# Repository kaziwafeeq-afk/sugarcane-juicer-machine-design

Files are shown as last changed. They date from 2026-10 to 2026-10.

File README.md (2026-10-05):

# Design and Analysis of a Conventional Sugarcane Juicer Machine

A comprehensive machine design, MATLAB-automated calculations, and ANSYS structural analysis project for a commercial sugarcane juicer system.

---

## Project Overview
* **Objective:** Design and validate a compact, efficient roadside sugarcane juicer machine capable of handling commercial daily workloads.
* **Core Systems:** Electric motor drive (1.4 HP, 630 rpm), multi-stage pulley and gear reduction systems, crushing rollers, and a structural support frame.
* **Key Tools:** SolidWorks (CAD modeling), ANSYS (Static Structural FEA), MATLAB (Automated Gear Design and Calculations).

---

## Key Specifications & Performance
* **Machine Dimensions:** Height: 1.2 m, Breadth: 0.35 m, Length: 0.5 m.
* **Capacity & Yield:** Processes 20 kg/hour with an average juice yield of 250 ml/kg.
* **Daily Throughput:** Estimated output of 98 cups (24.5 liters) over a 7 hour working day at 70% operational efficiency.

---

## Engineering Methodology

1. **Power Transmission & Layout:**
   * Designed a multi-stage reduction using a 3-phase electric motor connected via pulley systems and gear trains (spur and pinion gears) to achieve high crushing torque at the rollers.
   * Developed automated MATLAB scripts to handle iterative gear sizing, module calculations, and stress validations without manual hand-calculation bottlenecks.

2. **Structural & FEA Analysis (ANSYS):**
   * Conducted static structural analyses on the structural steel side walls, gear teeth, and roller shafts under simulated loading and motor torque moments.
   * **Factor of Safety (FOS):** Maintained robust safety margins across components (e.g., FOS of 5.57 on the main support structure and 15 on gear/pulley subcomponents under exaggerated peak loads).

---

## Assembly Render

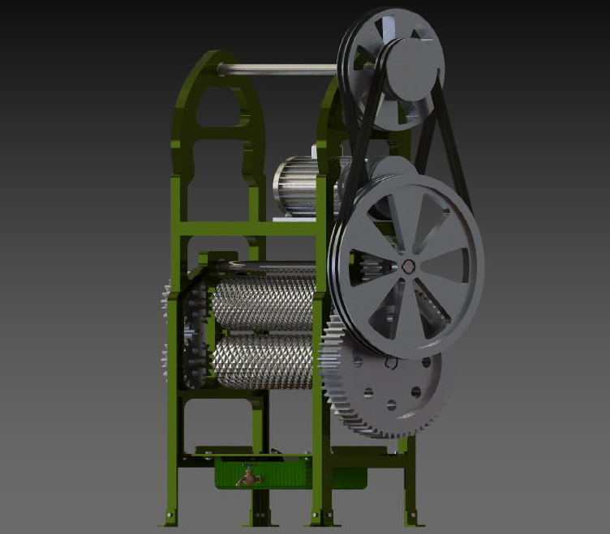
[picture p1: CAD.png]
Sugarcane Juicer CAD Assembly


---

## Documentation & Repository Structure
* **[Download & View Full Project Report (PDF)](./DMS%20ASSIGNMENT%201-1.pdf)**: Complete documentation including detailed calculations, BOM, and ANSYS stress/deformation contour plots.
* `CAD.png`: Isometric assembly render of the machine.

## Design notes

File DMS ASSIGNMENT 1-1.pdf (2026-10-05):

### Member 1

### - Name: Ashutosh Mohapatra - Roll number: 211020003

### Member 2

### - Name: Taran Poojari - Roll number: 211020004

### Member 3

### - Name: Mohammed Wafeeq Kazi - Roll number: 211020022

## Assignment 1

## Design of Machine Elements Project

## Design and Analysis of a Conventional Sugarcane Juicer Machine

## The report outlines the following points –

1.Introduction.

2.Initial layout as per motor specifications.

## 3.Mounting structure, its Analysis

4.layout changes.

5.MATLAB Program for gear calculations.

6.Structural Analysis.

7.Bill Of Quantities.

8.Amount of sugarcane juice collected in a day.

9.Conclusion.

Introduction:

- Sugarcane juicer machines are one of the most common machines manufactured industrially due to the demands and high consumption of the conventional beverage in urban and suburban regions.
- The layout of a basic machine consists of a pulley system driven by an electric motor, which is further connected to a gear system, to which the final rollers are connected to obtain significant speed reduction and crushing power.
- The distance between the rollers is 10-15 mm, which is smaller than the diameter of the sugarcane itself, else the sufficient crushing force would not be developed while extracting the juice from the stalk.
- The roller distance can be varied with the help of a simple mechanism operated by a lead screw-based mechanism. For simplicity, the mechanism is not added in the project and only the fundamental elements are described in the given report. The pictures of a standard sugar cane juicer machine are below:

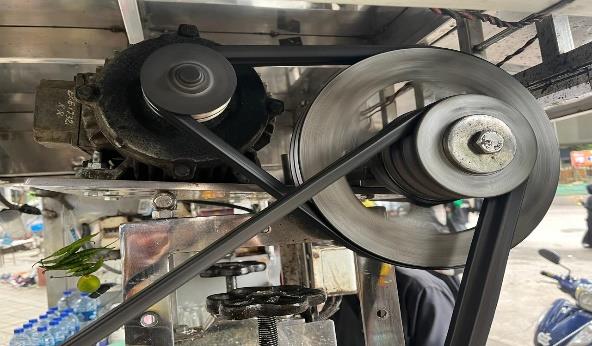
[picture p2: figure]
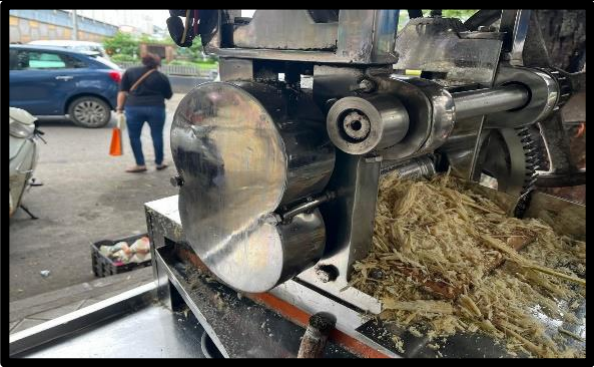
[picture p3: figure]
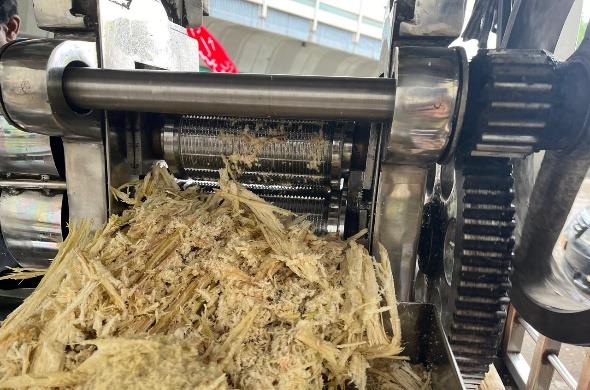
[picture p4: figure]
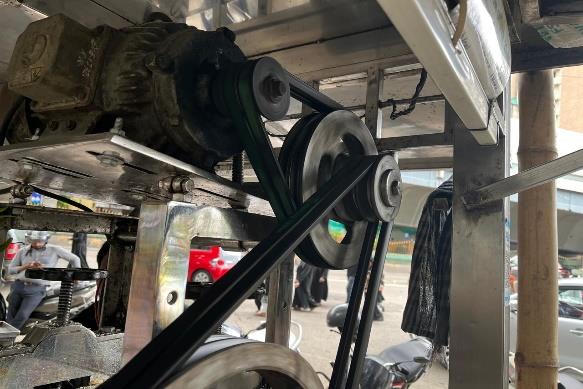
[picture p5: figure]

Initial Layout

- The motor specifications used for this project are as follows:
Type: | 3 - Phase Electric motor:
Power: | 1.4 HP
Speed: | 630 rpm
- Initial Model:

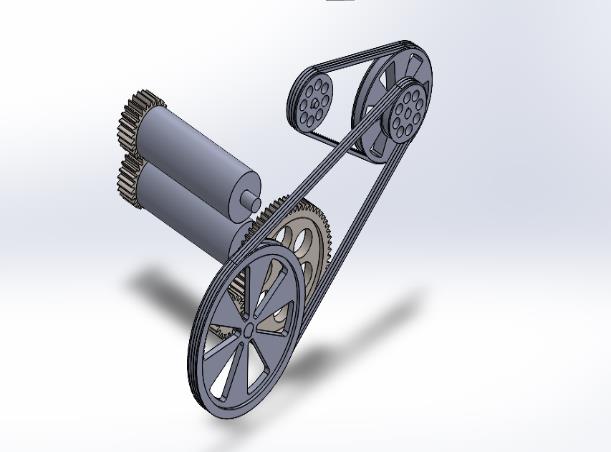
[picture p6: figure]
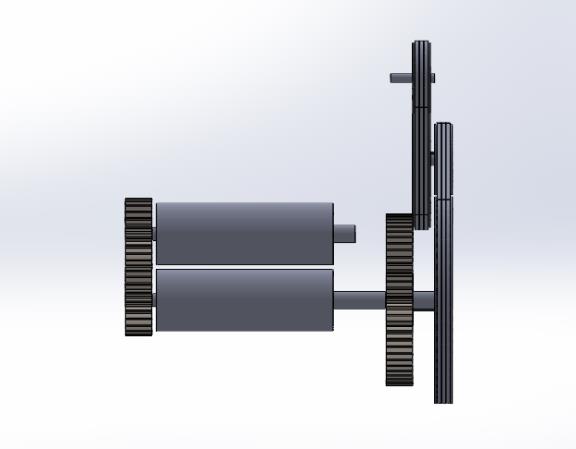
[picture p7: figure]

Fig: Isometric View. | Fig: Front View.

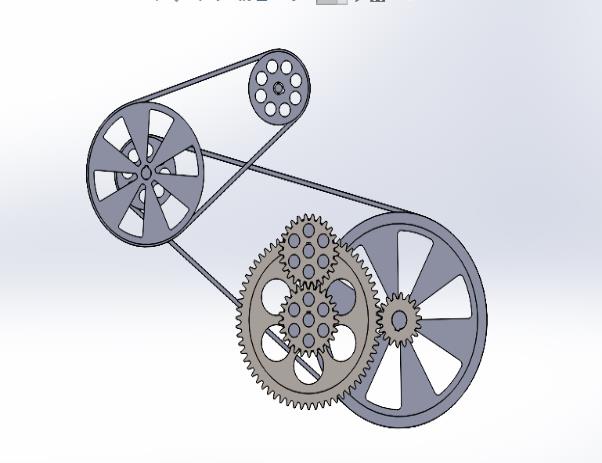
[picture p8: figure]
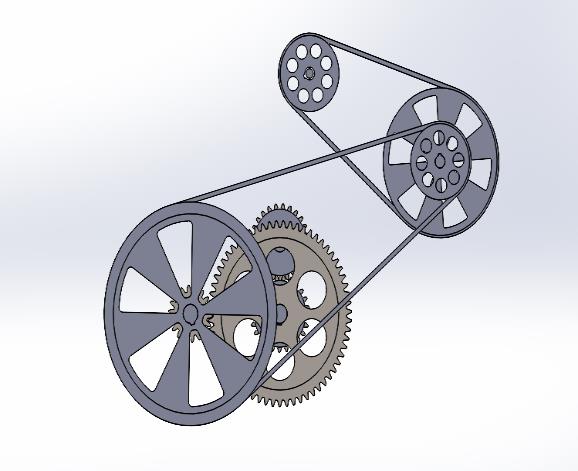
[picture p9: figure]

Fig: Left View | Fig: Right View
- Based on the calculations, the initial layout design was created in SolidWorks as follows.
- The supporting calculations are attached at the end of the report for both the gear and pulley systems.

SUPPORT STRUCTURE

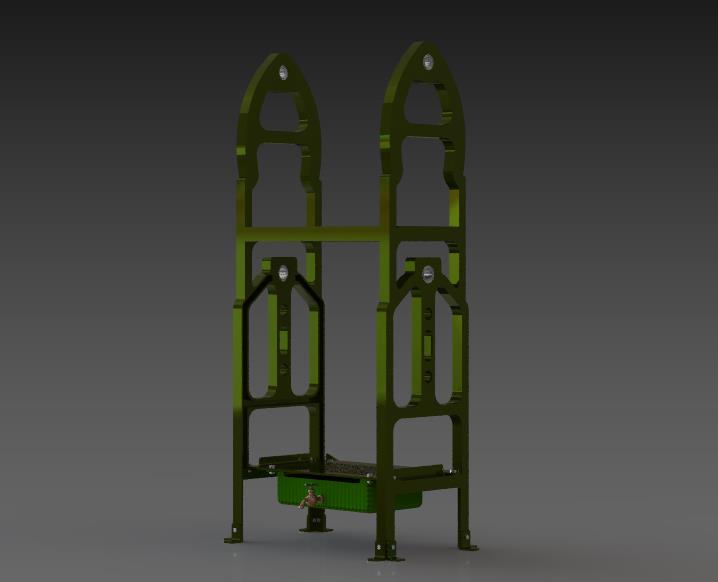
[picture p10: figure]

- The sugarcane machine features a support structure designed to hold the pulleys, gears, motors, and bearings securely in place. The structure includes four designated areas where rotating components are installed, each supported by bearings to ensure smooth operation.
- The upper base of the structure is responsible for supporting the motor, while the lower base incorporates a collection mechanism. When the sugarcane is crushed, the extracted juice flows into a container below. A strainer in this mechanism prevents sugarcane fibre’s from mixing with the juice.
- In this setup, the primary load is borne by the side walls of the structure. The loads on the collection chamber and motor base are considered minimal and not significant enough to impact the overall structural integrity.
- Therefore, we will be doing the Analysis of the side walls to ensure the stability of the structure.

Analysis of static structure which provides support to the crushing mechanism of the sugarcane machine:

- Material Used:
- Structural Steel is used for this purpose for providing robust support to the mechanisms.
- E = 200 GPa.
- P.R = 0.3.
- Analysis Settings:
- A: Fixed to the ground.
- B: Fixed to the ground.
- C: Moment due to presence of gear/ pulley.
- D: Moment due to presence of gear/ pulley.
- E: Moment due to presence of gear/ pulley.
- F: Moment due to presence of gear/ pulley.
- G: Load due to Collection mechanism.
- H: load due to motor.
- Note: Exaggerated loads and moments are applied as a factor of safety.

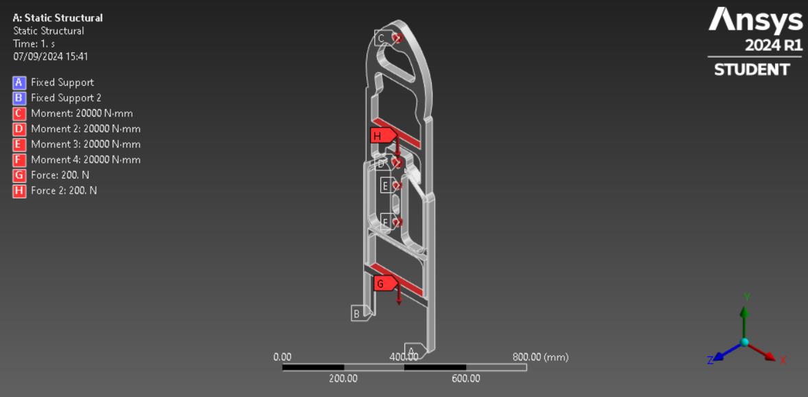
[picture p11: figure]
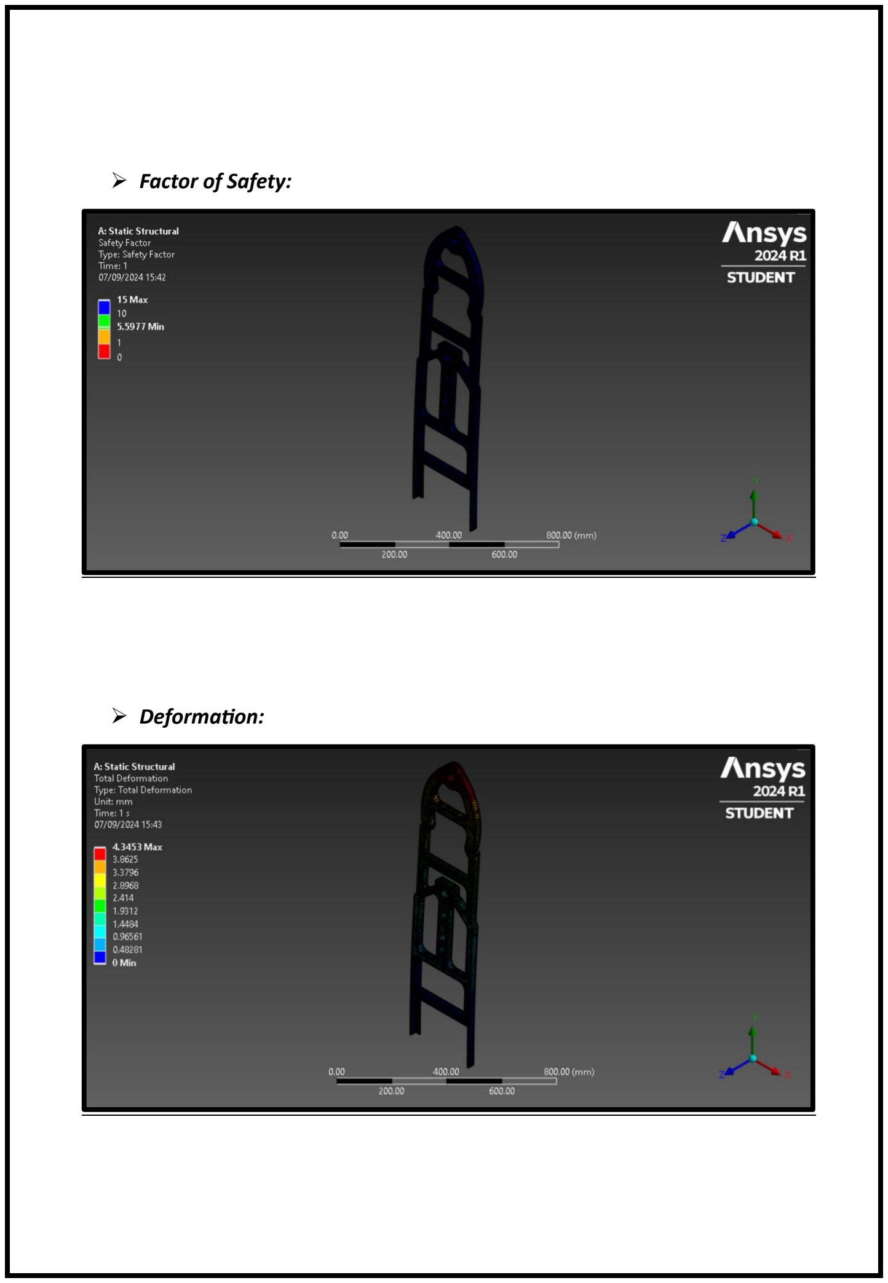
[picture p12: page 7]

- Factor of Safety:
- Deformation:

- Equivalent Stress:

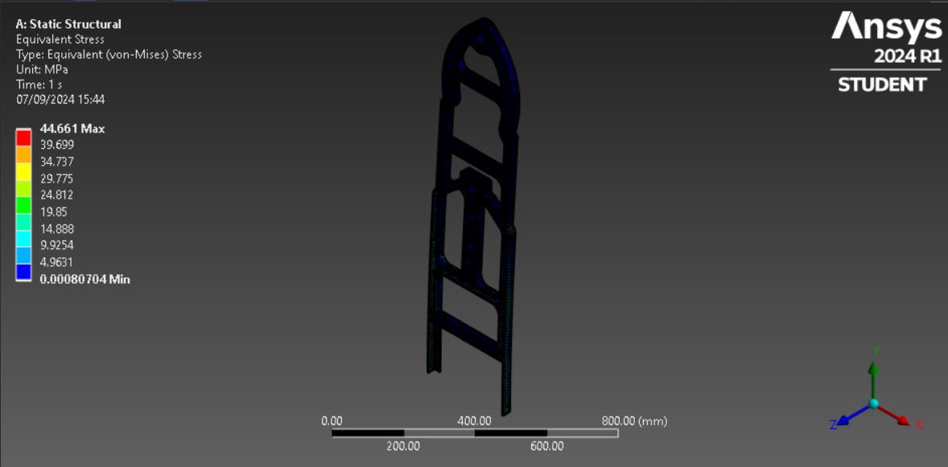
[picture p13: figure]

- Results:
- The mechanism will be able to sustain the applied load as the factor of safety is 5.57.
- The gears are supported using two side walls and the load in unevenly distributed on both sides.
- The analysis done is of the wall experiencing greater load. So therefore, we can say that the side experiencing less load in comparison to other side will also sustain.

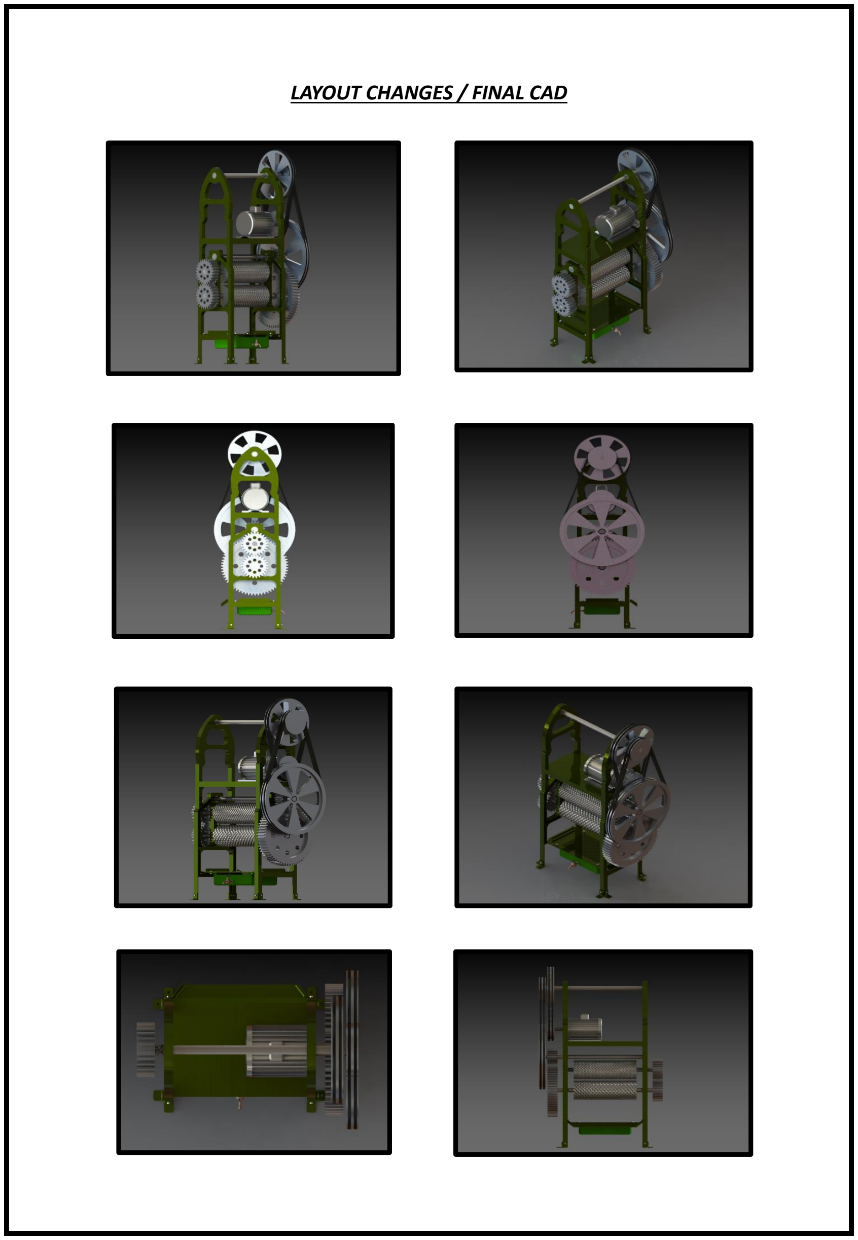
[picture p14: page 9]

LAYOUT CHANGES / FINAL CAD

Final CAD

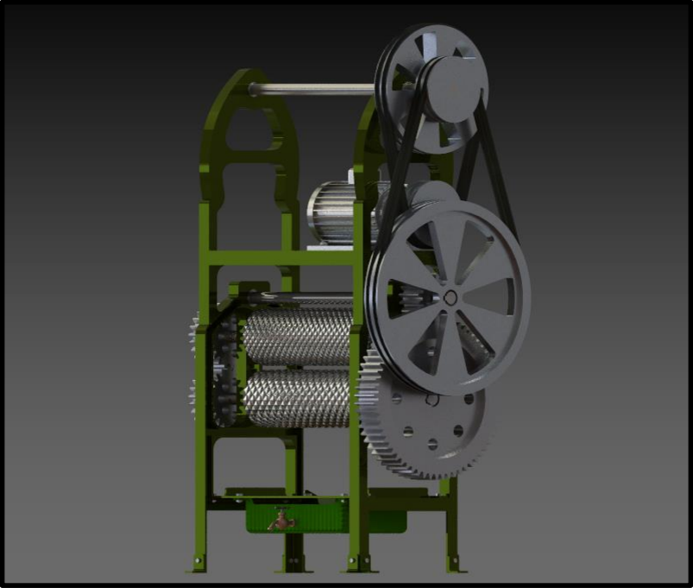
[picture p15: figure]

- The Mechanical System Comprising of pulleys, gears, rollers, support structure and motor where connected/assembled in such a way so as to provide a compact structure.
- The dimensions of the Sugarcane machine are roughly
- Height: 1.2 meter.
- Breadth: 0.35 meter.
- Length: 0.5 meter.
- The Components which will rotate are provided with bearings to provide a smooth frictionless Rotations.
- The Gears and Pulleys are mated with suitable keys to provide stable locking with interconnected shafts.
- The Rollers are provided with grooves which amplifies the crushing effect.
- A tap is fitted on the container, providing feasible collection of crushed juice.

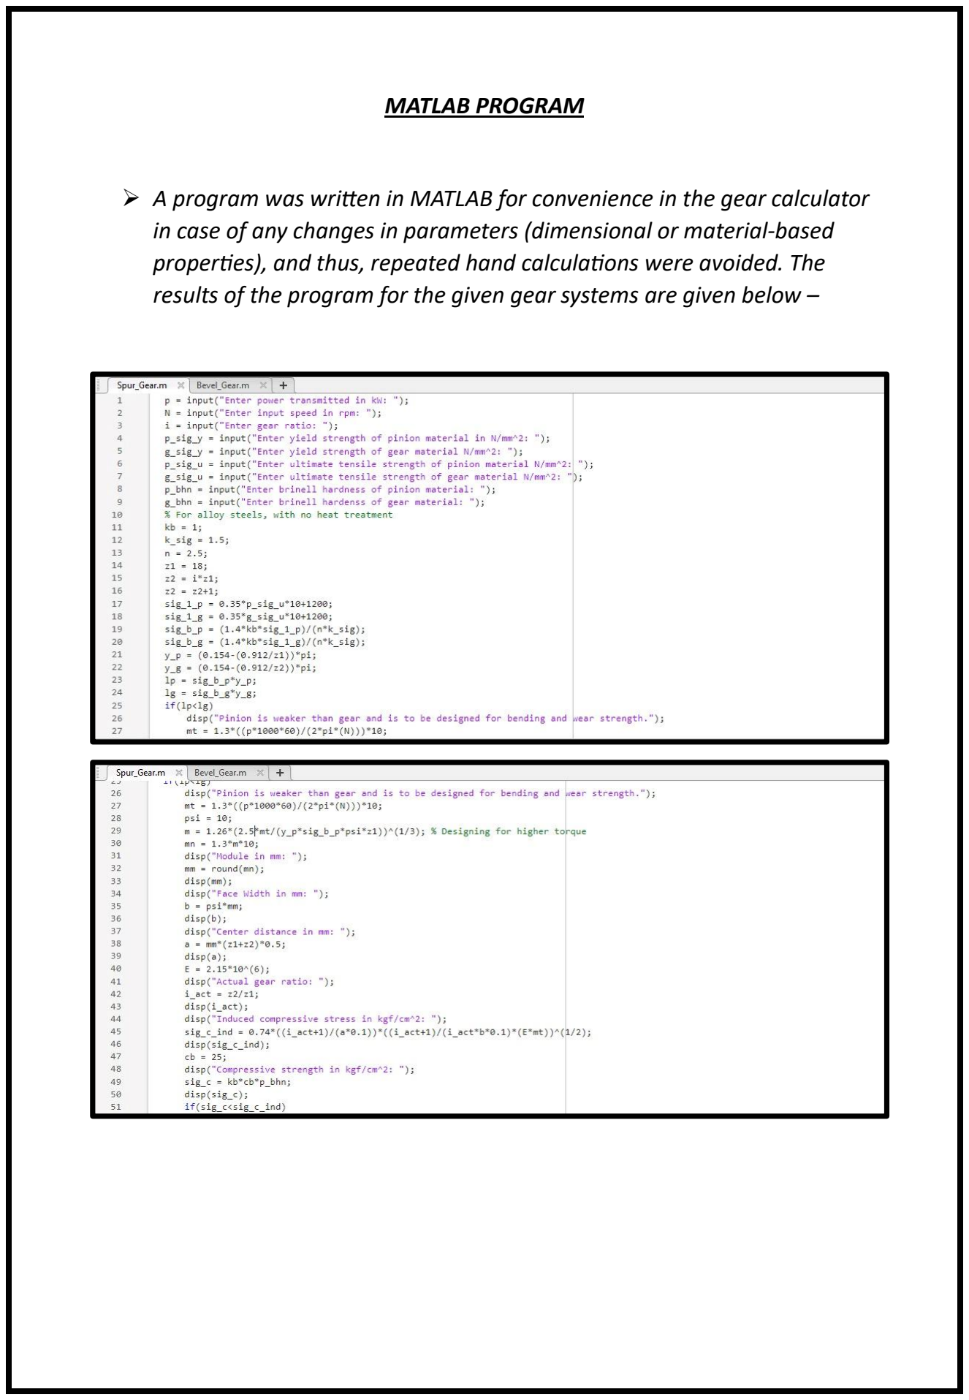
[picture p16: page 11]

MATLAB PROGRAM

- A program was written in MATLAB for convenience in the gear calculator in case of any changes in parameters (dimensional or material-based properties), and thus, repeated hand calculations were avoided. The results of the program for the given gear systems are given below –

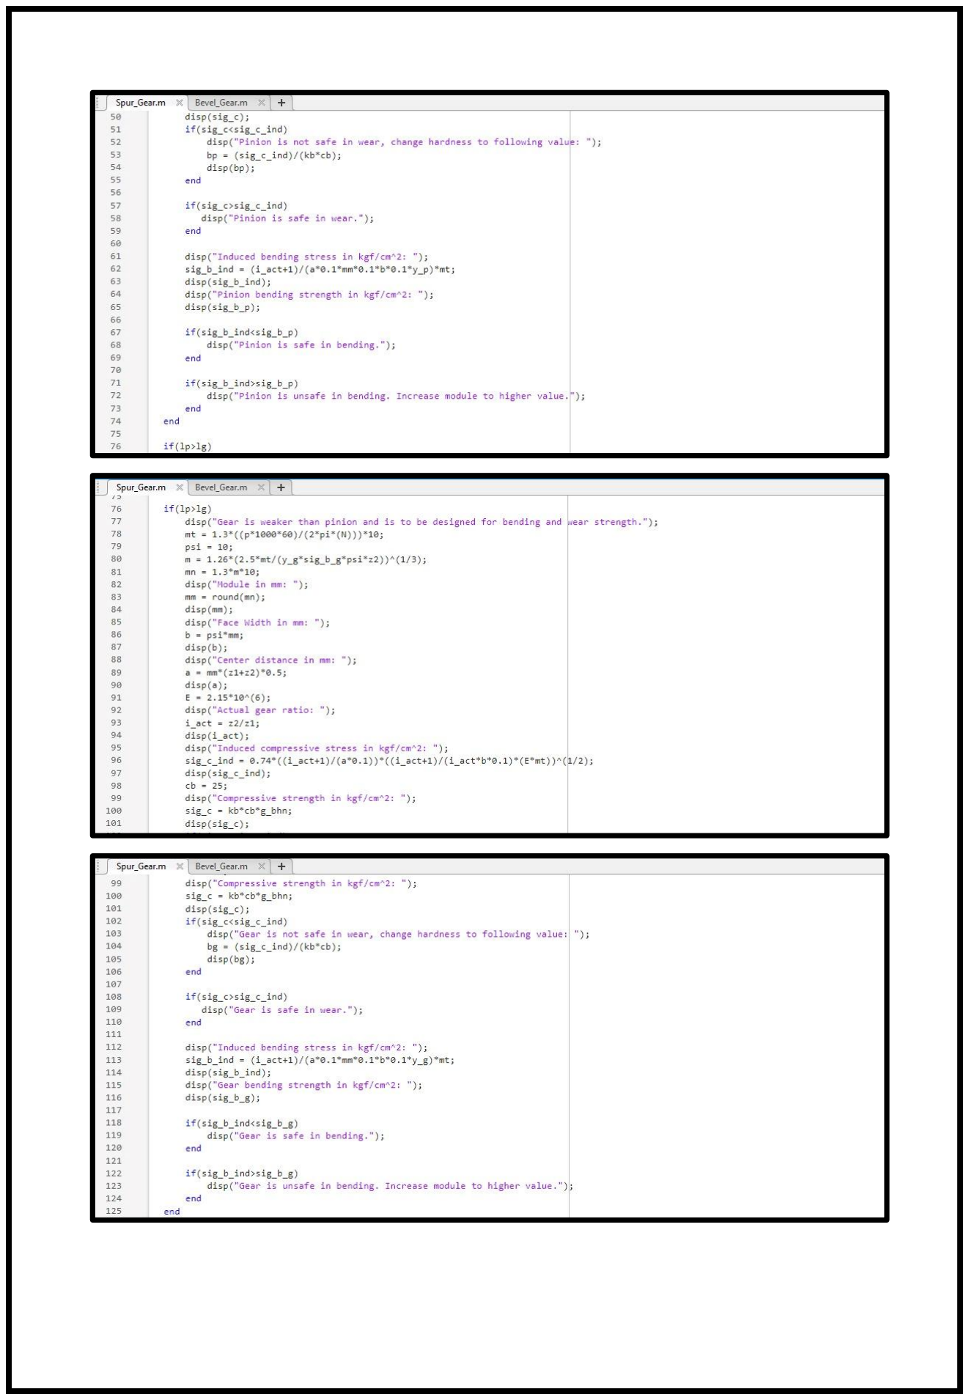
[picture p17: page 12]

- Results:

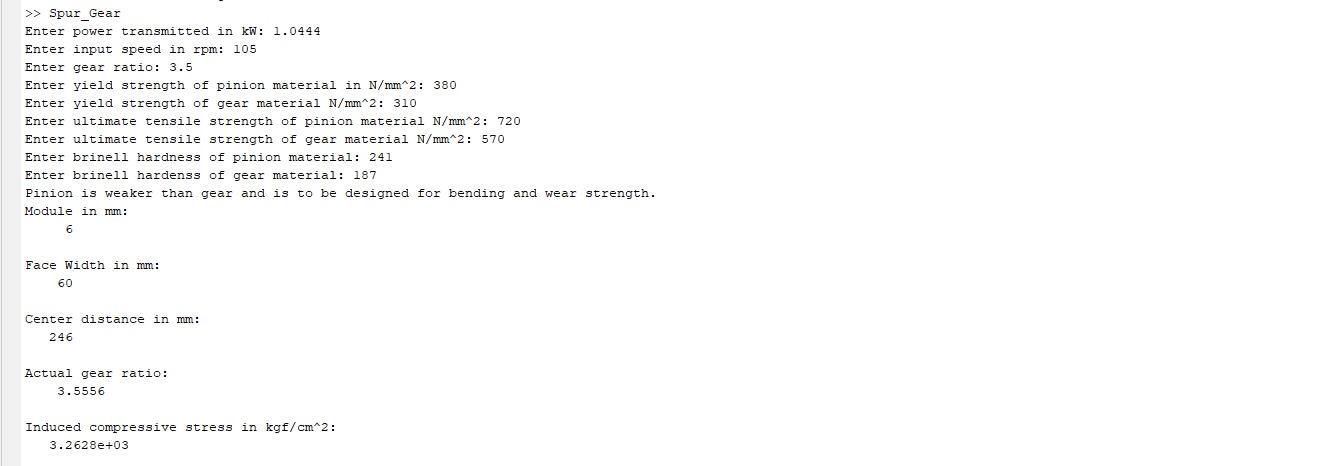
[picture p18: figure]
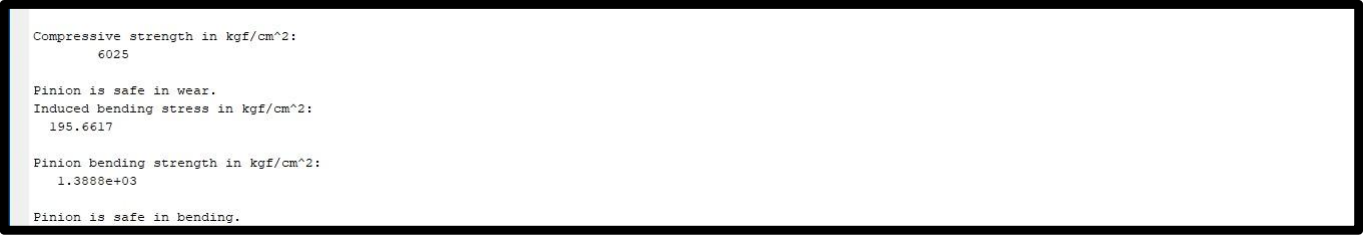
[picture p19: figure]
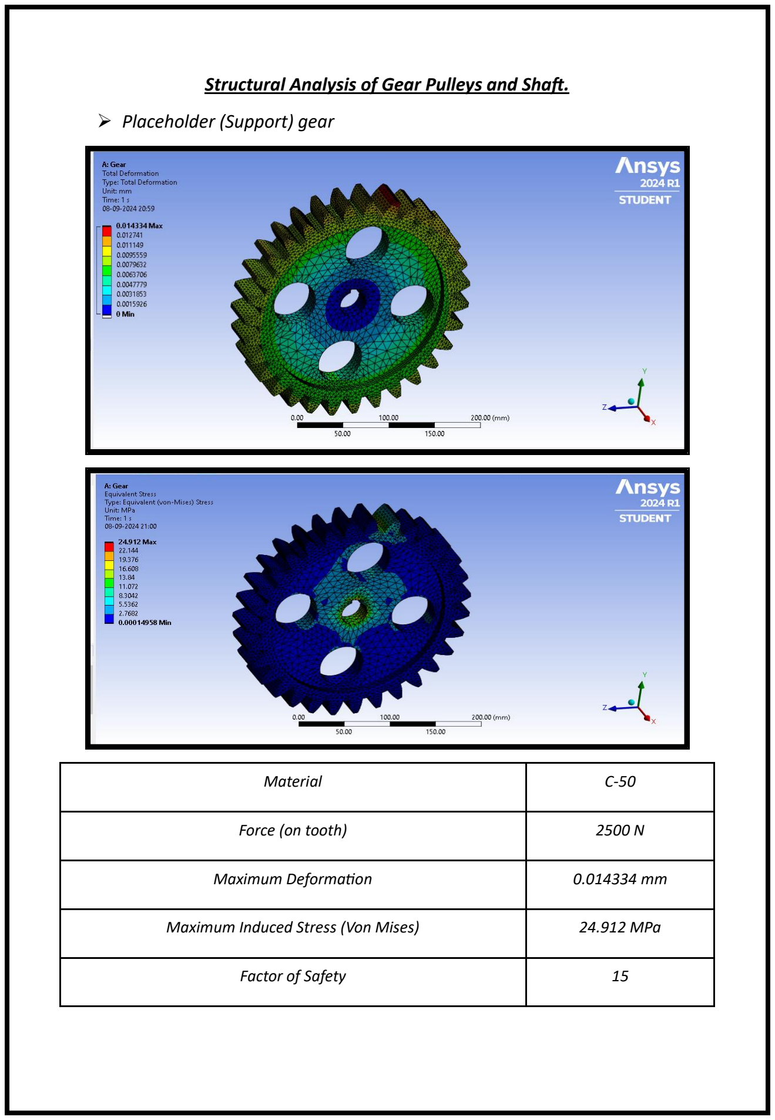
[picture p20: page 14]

Structural Analysis of Gear Pulleys and Shaft.

- Placeholder (Support) gear
Material | C-50
Force (on tooth) | 2500 N
Maximum Deformation | 0.014334 mm
Maximum Induced Stress (Von Mises) | 24.912 MPa
Factor of Safety | 15

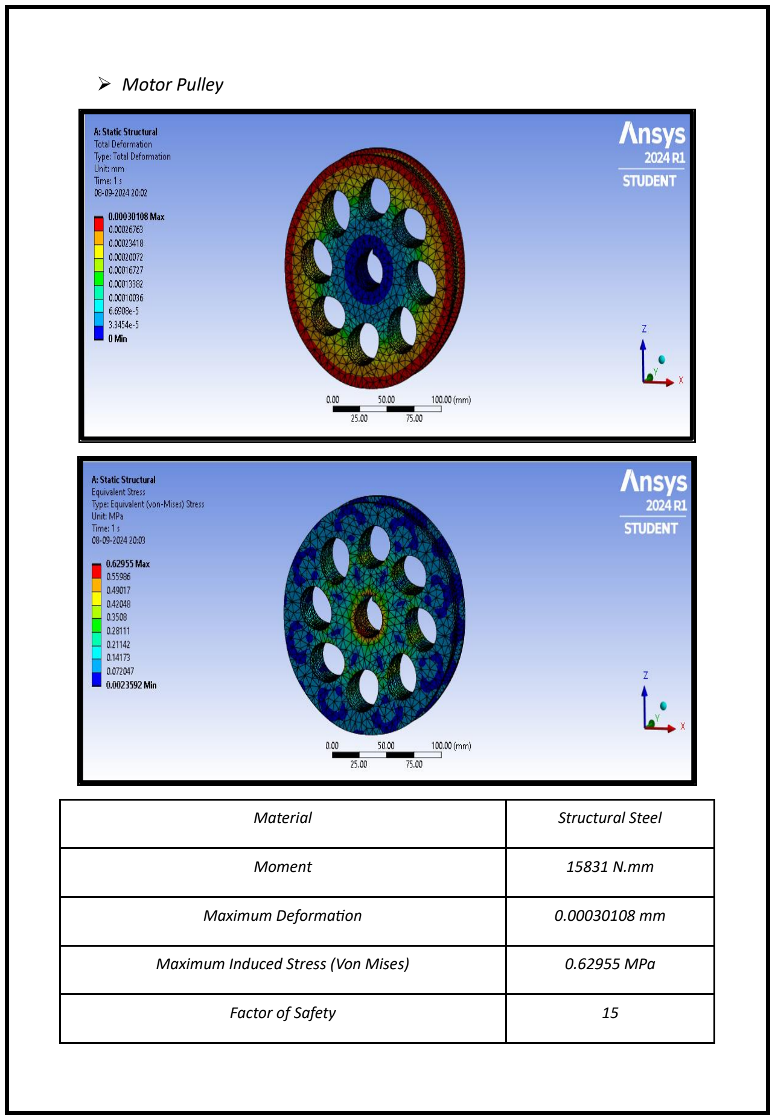
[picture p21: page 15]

- Motor Pulley
Material | Structural Steel
Moment | 15831 N.mm
Maximum Deformation | 0.00030108 mm
Maximum Induced Stress (Von Mises) | 0.62955 MPa
Factor of Safety | 15

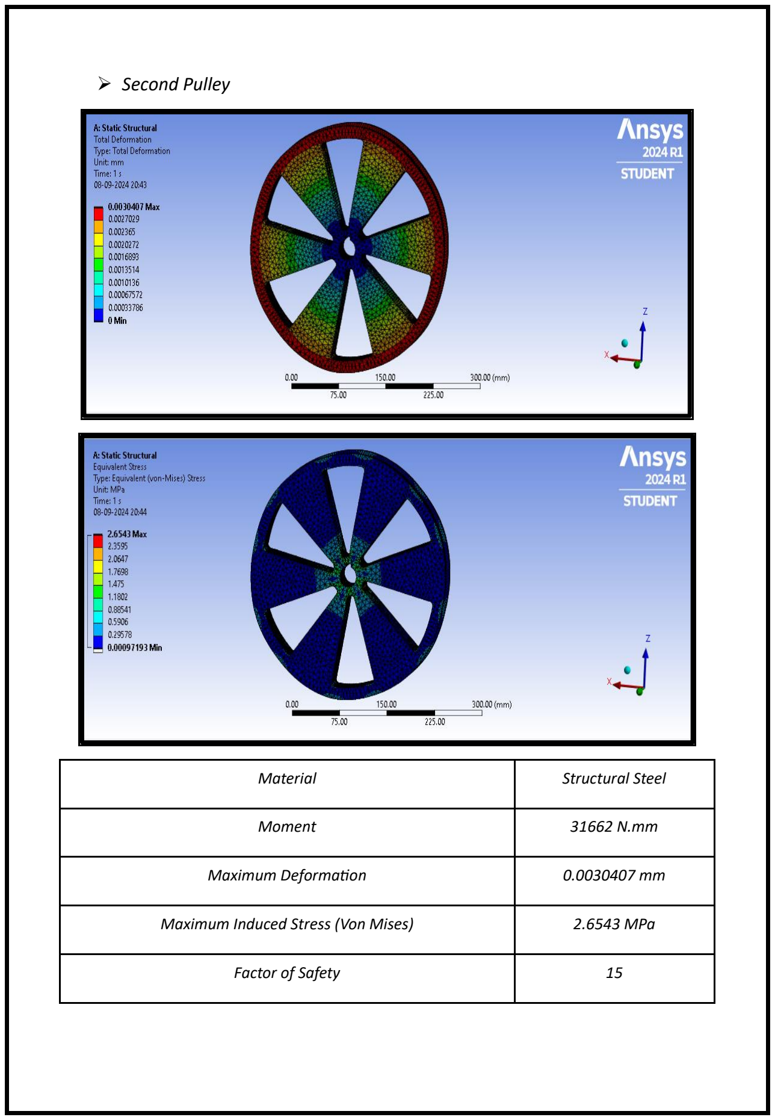
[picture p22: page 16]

- Second Pulley
Material | Structural Steel
Moment | 31662 N.mm
Maximum Deformation | 0.0030407 mm
Maximum Induced Stress (Von Mises) | 2.6543 MPa
Factor of Safety | 15

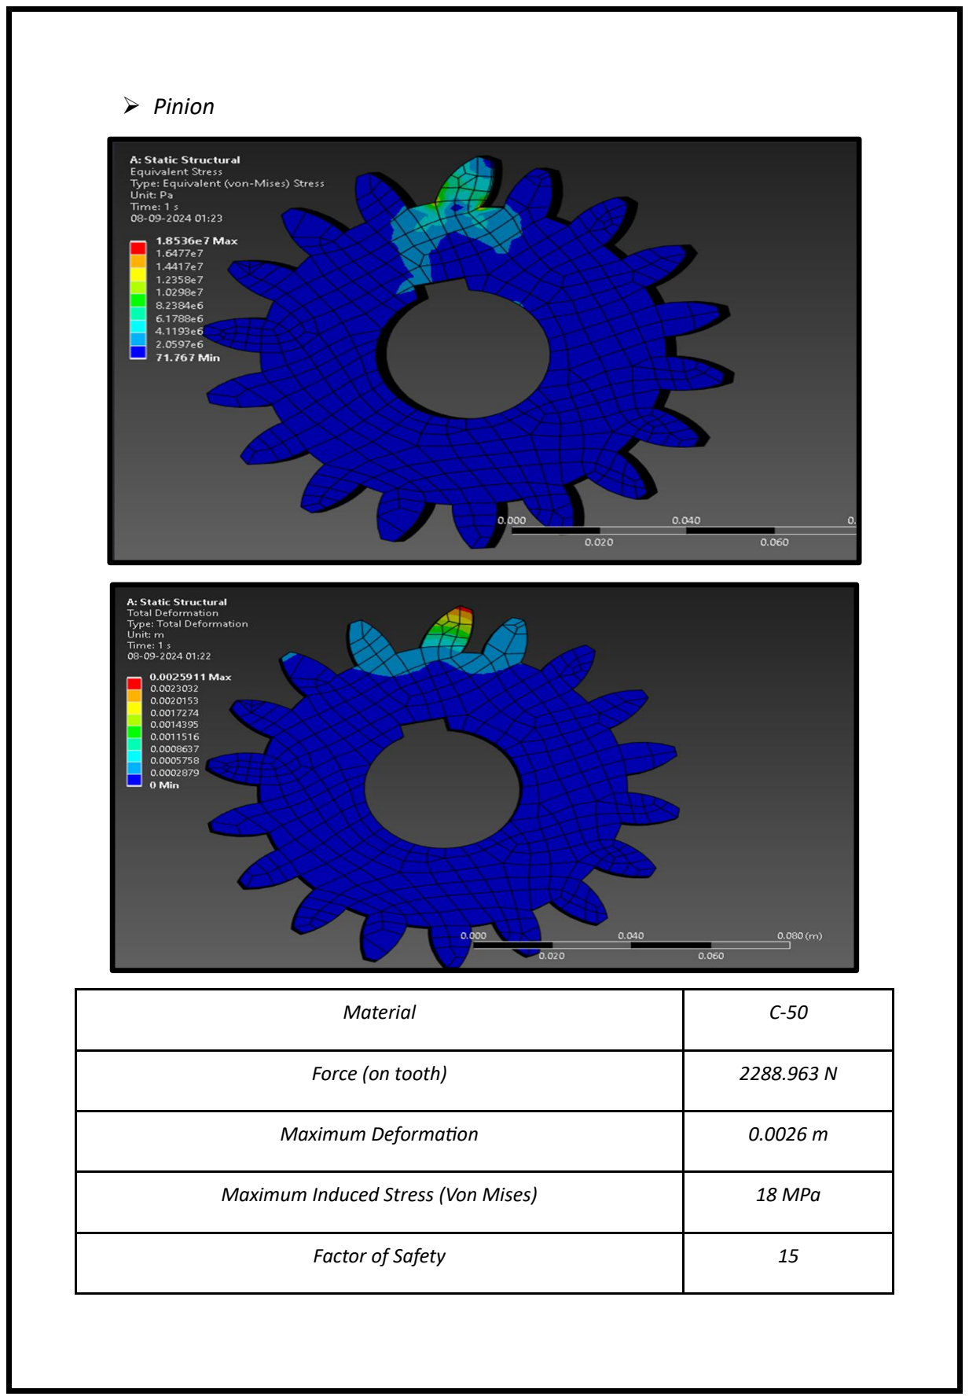
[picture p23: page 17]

- Pinion
Material | C-50
Force (on tooth) | 2288.963 N
Maximum Deformation | 0.0026 m
Maximum Induced Stress (Von Mises) | 18 MPa
Factor of Safety | 15

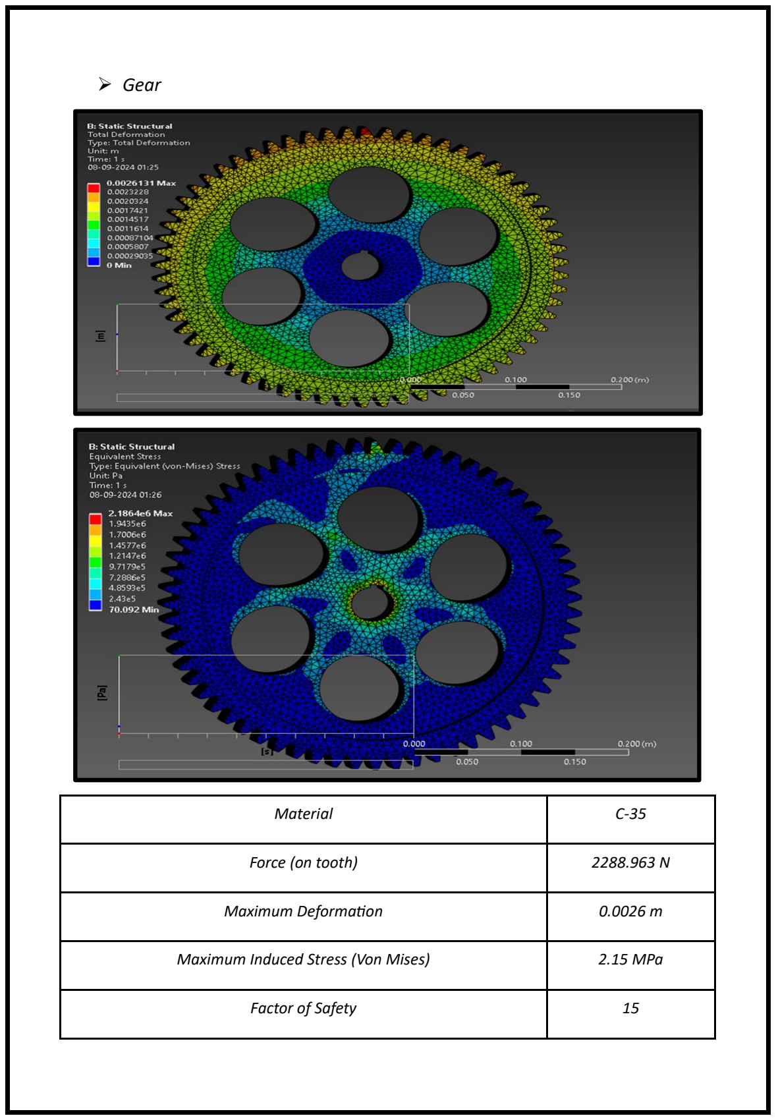
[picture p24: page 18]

- Gear
Material | C-35
Force (on tooth) | 2288.963 N
Maximum Deformation | 0.0026 m
Maximum Induced Stress (Von Mises) | 2.15 MPa
Factor of Safety | 15

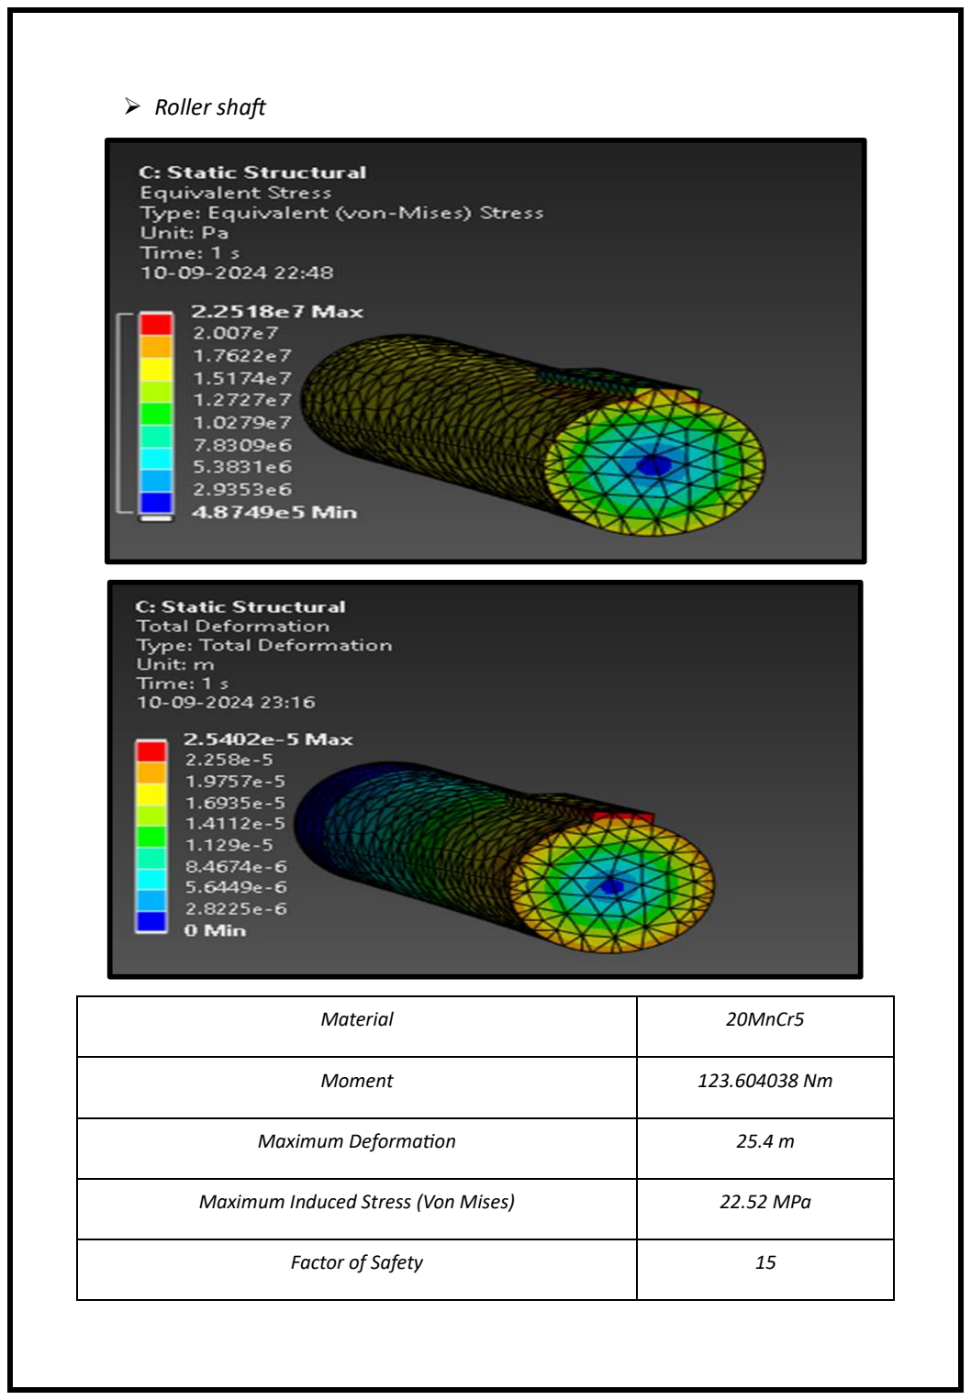
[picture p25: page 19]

- Roller shaft
Material | 20MnCr5
Moment | 123.604038 Nm
Maximum Deformation | 25.4 m
Maximum Induced Stress (Von Mises) | 22.52 MPa
Factor of Safety | 15

Bill Of Materials

PART NAME | MATERIAL | QUANTITY | COST PER PIECE | TOTAL COST
Pulleys (stage-1). | Structural Steel | 1 | ₹4,000 | ₹4,000
Pulleys (stage-2). | Structural Steel | 1 | ₹4,000 | ₹4,000
Pinion Gear. | C-50 | 1 | ₹5,000 | ₹5,000
Main Gear. | C-35 | 1 | ₹4,000 | ₹4,000
Placeholder Gear. | C-50 | 1 | ₹4,500 | ₹4,500
Shaft. | C-45 | 4 | ₹1500 | ₹6,000
Key. | C-45 | 8 | ₹250 | ₹2,000
Belt. | Canvas | 4 | ₹625 | ₹2500
Nuts and Bolts. | | 30 | ₹10 | ₹300
Bearings. | | 16 | ₹500 | ₹8000
Motors. | | 1 | ₹6000 | ₹6000
- Total cost: ₹46300.
- Total cost with added miscellaneous costs: ₹50,000 Approx.
- It is important to note that these costs are Approximate costs and are can be subjected to change.

Number of cups filled on an average:

- Working hours: 7 hours.
- Worker efficiency: 70 percent.
- Capacity of machine: 20 kg/hour.
- Amount of juice extracted from one sugarcane: 250ml/kg.
- Effective operating time is: 7 x 0.7 = 4.9 hours.
- Total sugarcane crushed in a day: 4.9 x 20 = 98 kg.
- Total juice collected: 98 x 250 = 24500 ml.
- Number of cups fill: 24500 / 250 = 98 cups.
- Number of customers are not taken into consideration as amount of juice extracted depends on the number of customers visited.
- This calculation was done to find out how much on an average a sugarcane vendor can extract.

Conclusion.

- The design of the roadside sugarcane machine effectively balances portability, ease of operation, and juice extraction efficiency. With a capacity of 20 kg/hour and an average juice yield of 250 ml per kg, the machine is suitable for single-labourer operation, typical of street vending environments. Over the course of a 7-hour workday, with a labour efficiency of 70%, the machine processes approximately 98 kg of sugarcane, producing 24.5 litters of juice, which is sufficient to fill 98 cups of 250 ml each.
- The machine's performance is optimized for manual operation, taking into account the worker’s multitasking duties and potential downtimes. The moderate capacity ensures that the machine is manageable for a single operator, allowing for efficient throughput without overwhelming the worker. Additionally, the machine’s design is robust enough for continuous use, but compact and simple enough to require minimal maintenance in roadside environments.
- This design is ideal for small-scale sugarcane juice vendors, ensuring a balance between production efficiency and labour costs.

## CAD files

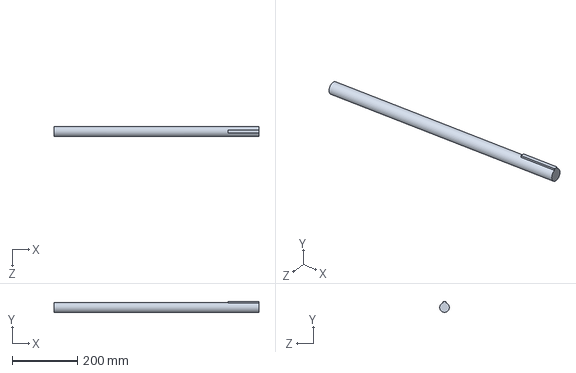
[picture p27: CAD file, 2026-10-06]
Solidworks/10_ROD.SLDPRT
630.0 x 33.3 x 30.0 mm

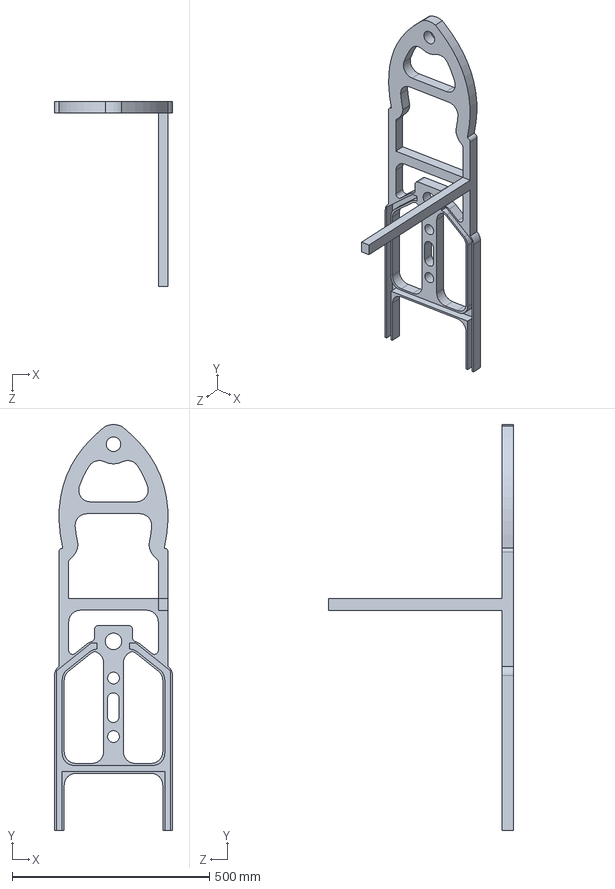
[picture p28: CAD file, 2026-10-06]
Solidworks/7_SIDE PART.SLDPRT
300.0 x 1029.8 x 470.0 mm

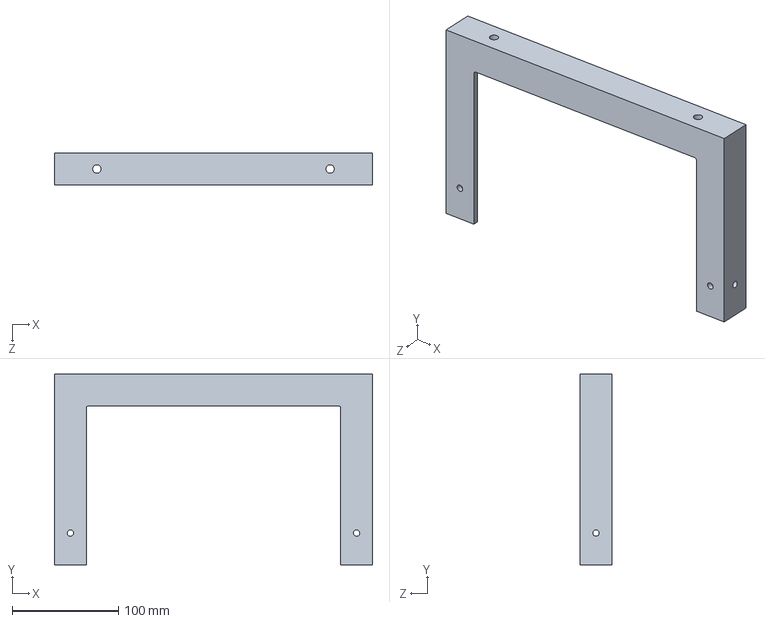
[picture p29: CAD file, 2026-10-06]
Solidworks/1_BASE BARS.SLDPRT
300.0 x 180.0 x 30.0 mm

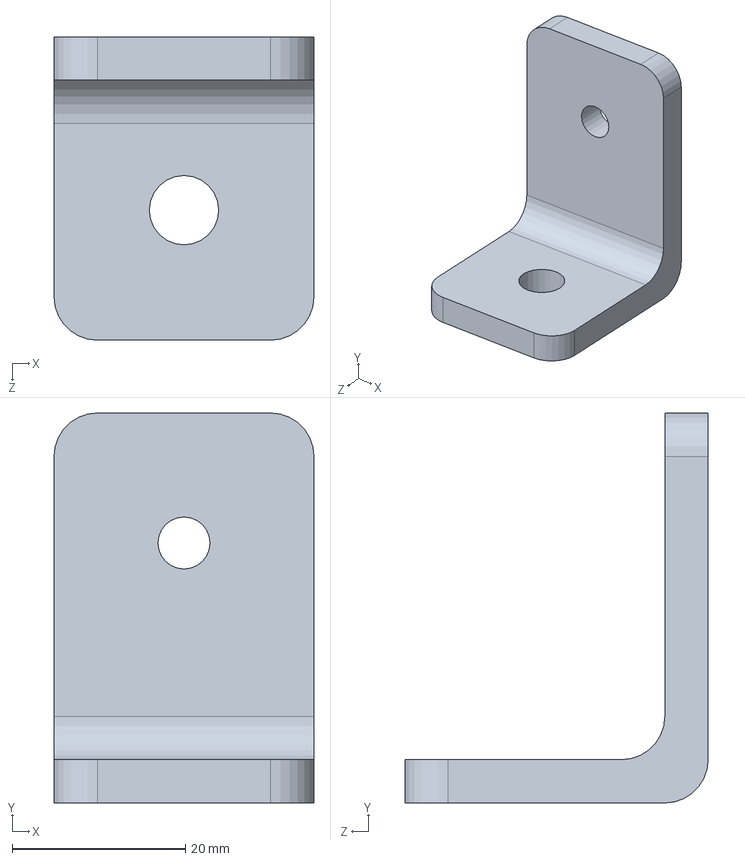
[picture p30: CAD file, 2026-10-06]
Solidworks/4_L BRACKETS.SLDPRT
30.0 x 45.0 x 35.0 mm

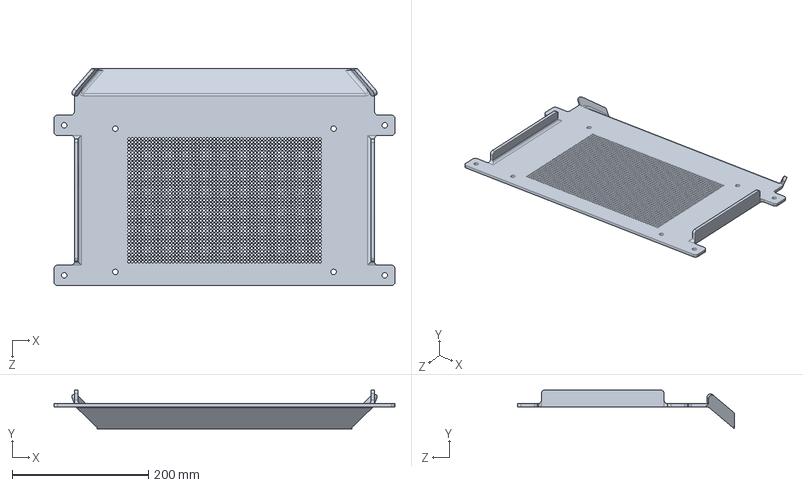
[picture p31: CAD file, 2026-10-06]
Solidworks/2_SEPERATOR.SLDPRT
500.0 x 57.1 x 318.3 mm

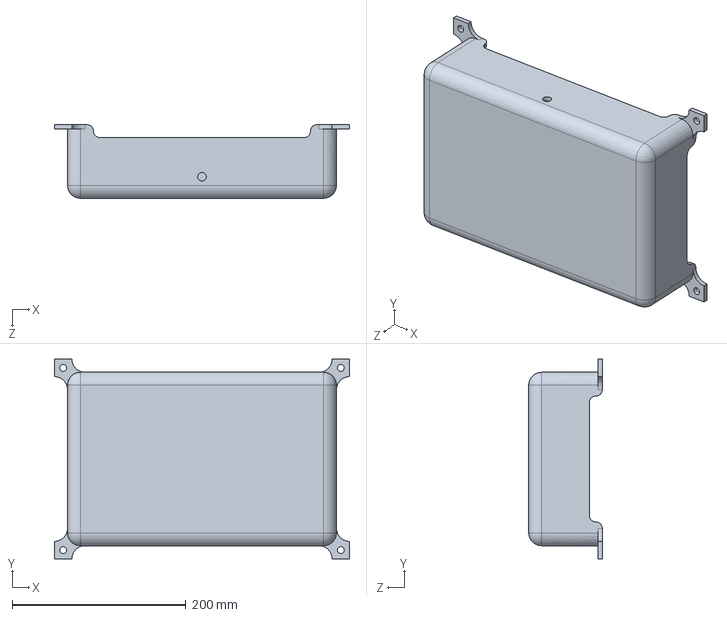
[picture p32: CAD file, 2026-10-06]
Solidworks/3_JUICE COLLECTOR.SLDPRT
340.0 x 230.0 x 85.0 mm

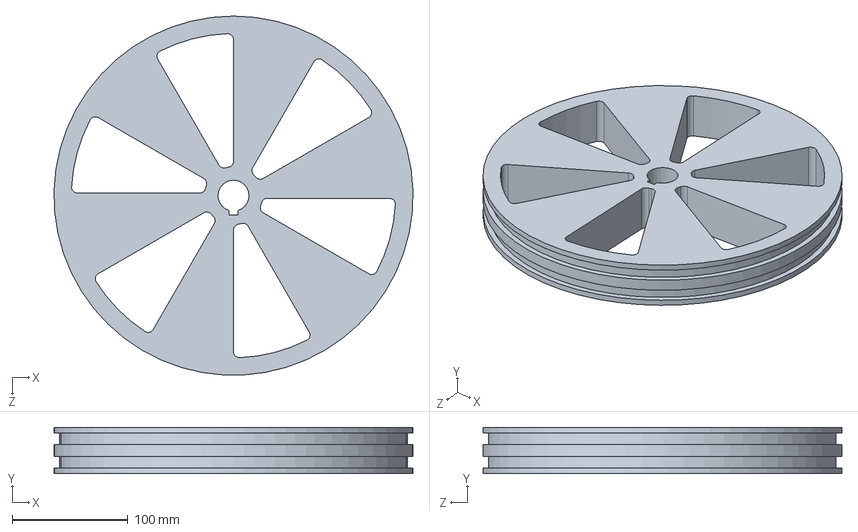
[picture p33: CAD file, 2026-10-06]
Solidworks/Pulley_2.SLDPRT
309.9 x 40.0 x 309.7 mm

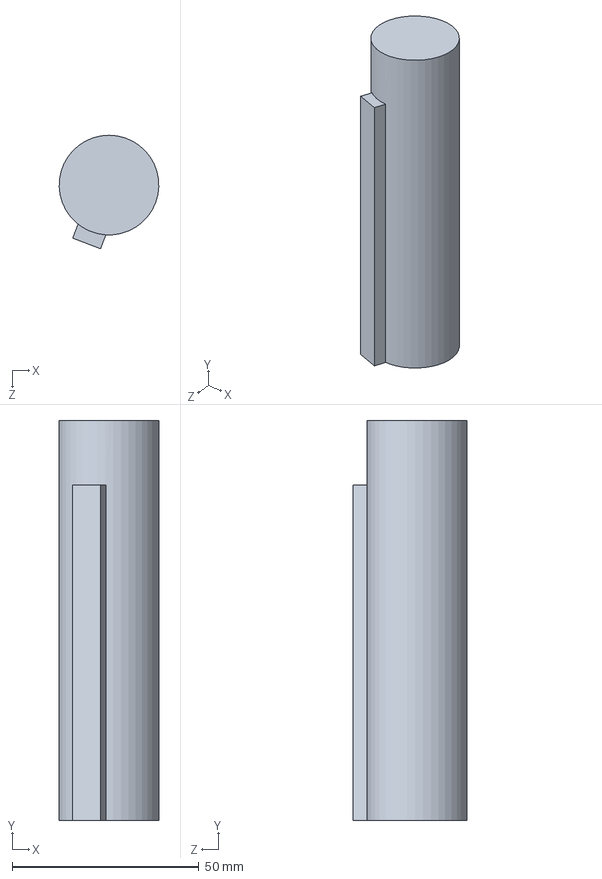
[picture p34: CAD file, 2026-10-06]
Solidworks/17_MOTOR SHAFT.SLDPRT
26.7 x 107.2 x 30.4 mm

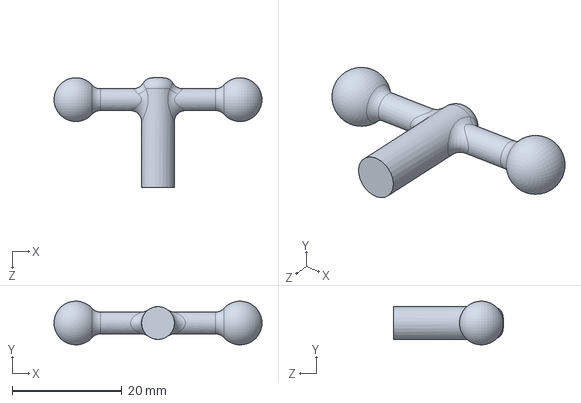
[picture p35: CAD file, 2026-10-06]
Solidworks/6_TAP HEAD.SLDPRT
38.0 x 7.99 x 20.0 mm

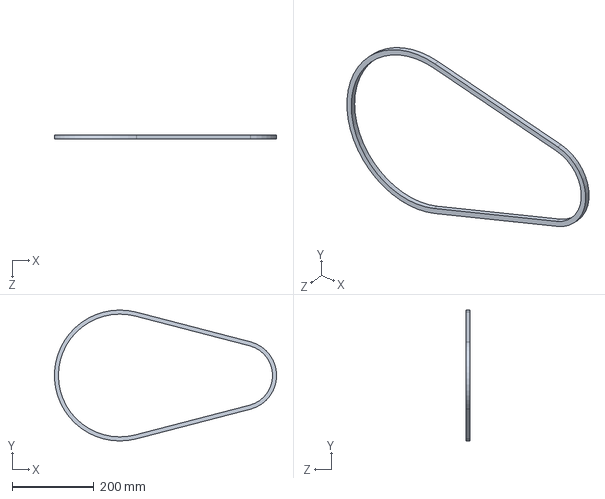
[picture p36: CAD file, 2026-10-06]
Solidworks/18_BELT 2.SLDPRT
542.6 x 320.0 x 10.0 mm

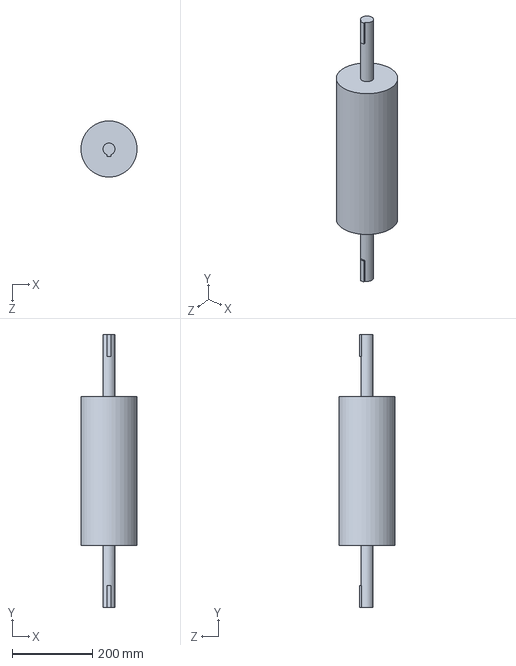
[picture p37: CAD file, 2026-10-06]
Solidworks/9_ROLLER 2.SLDPRT
139.9 x 680.0 x 140.0 mm

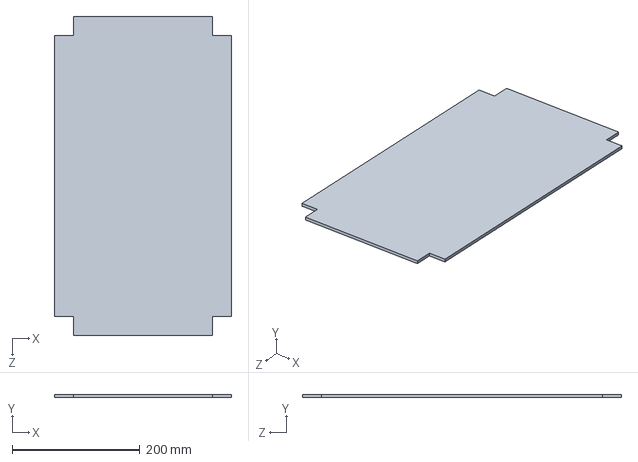
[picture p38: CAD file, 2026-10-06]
Solidworks/16_MOTOR BASE.SLDPRT
277.5 x 5.00 x 500.0 mm

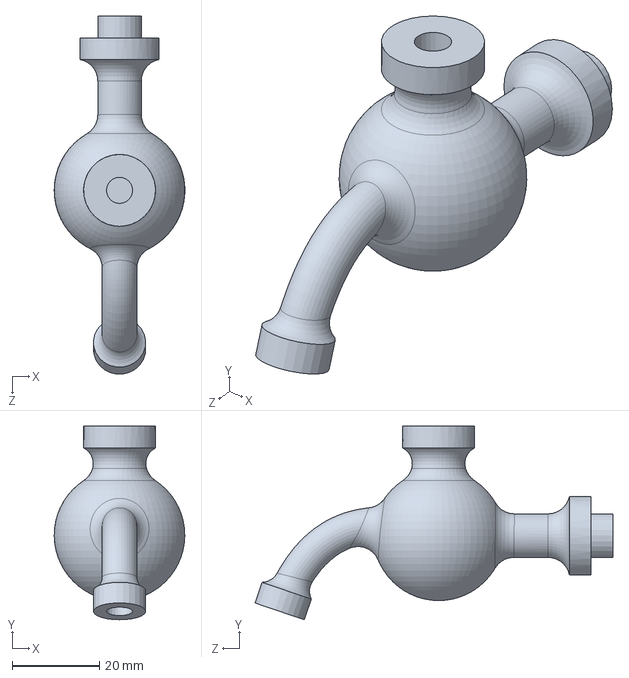
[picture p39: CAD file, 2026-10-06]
Solidworks/5.SLDPRT
30.0 x 44.4 x 82.1 mm

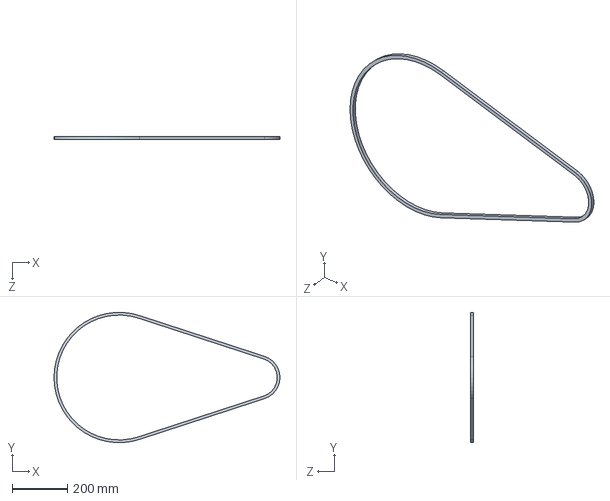
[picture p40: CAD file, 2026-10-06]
Solidworks/14_BELT 1.SLDPRT
815.0 x 469.1 x 10.0 mm

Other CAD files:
Solidworks/8_ROLLER 1.SLDPRT
Solidworks/spur gear_am_2.SLDPRT
Solidworks/Pulley_3.SLDPRT
Solidworks/15_MOTOR.SLDPRT
Solidworks/2_Pulley_Shaft.SLDPRT
Solidworks/8_ROLLER 1.IGS
Solidworks/9_ROLLER 2.IGS
Solidworks/Motor_Pulley.SLDPRT
Solidworks/formed hex screw_am.sldprt
Solidworks/hex nut jam_am.sldprt
Solidworks/instrument ball bearing_68_am.sldprt
